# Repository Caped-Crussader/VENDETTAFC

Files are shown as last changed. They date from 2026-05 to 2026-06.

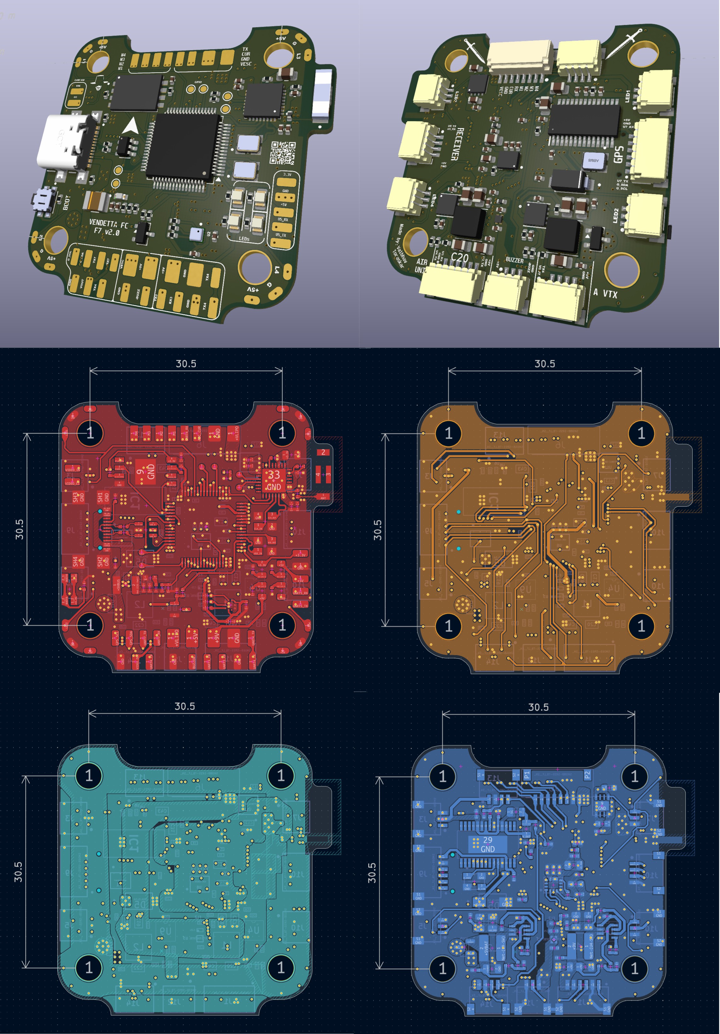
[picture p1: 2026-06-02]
VFC/imagerev2.jpg

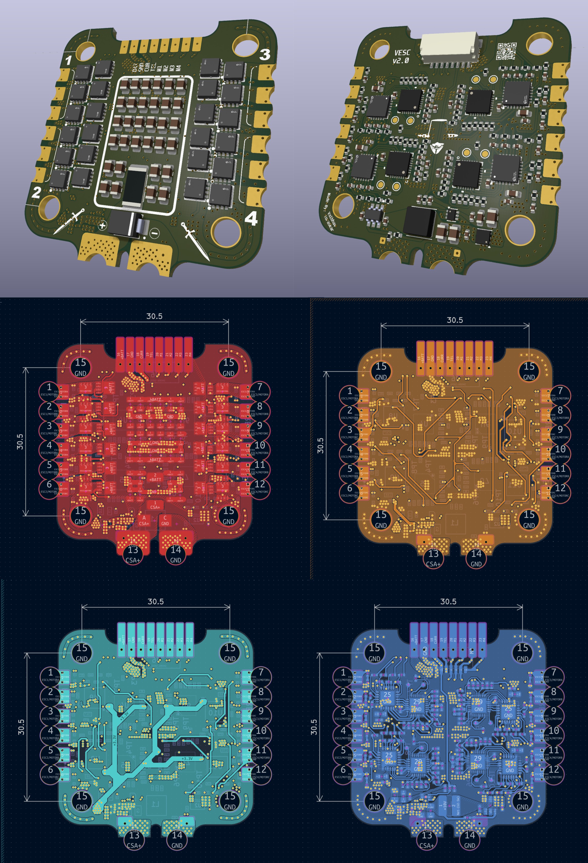
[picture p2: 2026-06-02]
VESC/imagerev2.jpg

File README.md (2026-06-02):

# VENDETTA FPV Stack

> A fully open-source, custom-designed 4-in-1 ESC and F7 Flight Controller stack for FPV multirotors, designed from scratch in KiCad.





---

## Overview

The VENDETTA stack consists of two boards designed to work together as a matched pair, built around modern components and open firmware with no proprietary dependencies.

| Board | Folder | Status |
|---|---|---|
| VENDETTA ESC (VESC) | `/VESC` | Schematic complete, layout WIP |
| VENDETTA FC (VFC) | `/VFC` | Schematic complete, layout WIP |

---

## VENDETTA ESC (VESC)

A 30×30mm 4-in-1 ESC (25A x 4) designed for 3–6S FPV multirotors.

imagerev2

> Note: 6 Layer Board, GND (plane 2 and 5) plane photos not included.

### Specifications

| Parameter | Value |
|---|---|
| MCU | Artery AT32F421GBU7 |
| Gate Driver | NSG2065Q |
| MOSFETs | SP40N03GNJ (×6 per channel, 24 total) |
| Continuous current | 25A per channel |
| Burst current | 30A per channel |
| Input voltage | 3–6S LiPo (12.6V–25.2V) |
| Motor outputs | 4× 3-phase BLDC |
| Firmware | AM32 |
| Protocols | DShot150 / DShot300 / DShot600 |
| Telemetry | Bidirectional DShot (RPM) |
| Current sensing | INA185 + 0.5mΩ Kelvin shunt |
| TVS protection | SMBJ30A |
| Bulk capacitance | 320µF (32× 10µF MLCC) |
| BEC (8V) | MP9943GQ-Z |
| BEC (3.3V) | TLV76733 |
| Mounting | 30×30mm M3 |
| Connector | JST SH 1.0mm 8-pin (SM08B-SRSS-TB) |

### ESC Block Diagram

```
LiPo ──→ TVS + Bulk Caps ──→ 4× Half-Bridge (NSG2065Q + SP40N03GNJ)
                           ──→ 8V BEC ──→ Gate Driver VCC
                           ──→ Shunt (0.5mΩ Kelvin) ──→ INA185 ──→ AT32F421
AT32F421 ──→ DShot (from FC) ──→ PWM generation ──→ NSG2065Q ──→ Motors
```

---

## VENDETTA FC (VFC)

A 30×30mm F7 Flight Controller targeting feature parity with commercial boards like the SpeedyBee F7 V3, with improvements in IMU performance and power isolation.

imagerev2

> Note: 6 Layer Board, GND (plane 2 and 5) plane photos not included.

### Specifications

| Parameter | Value |
|---|---|
| MCU | STM32F722RETx (216MHz Cortex-M4) |
| IMU | ICM-42688-P (32kHz gyro, SPI) |
| Barometer | BMP388 (I2C) |
| Blackbox | W25N04KVZEIR (512MB NAND Flash, SPI) |
| Wireless | ESP32-C3 (WiFi + BT via UART1) |
| OSD | None (digital OSD via MSP DisplayPort) |
| Firmware | Betaflight |
| Motor outputs | 4× DShot (TIM2 CH1–CH4, PA0–PA3) |
| UARTs | 6× (UART3 OSD, UART4 DJI RX, UART5 ELRS, UART6 GPS, UART7 spare) |
| I2C | 1× (GPS compass) |
| USB | USB-C (USB 2.0 FS) |
| BEC (9V/2A) | MP9943GQ-Z |
| BEC (5V/3A) | MP9943GQ-Z |
| LDO Digital (3.3V/1A) | AP7361C |
| LDO Analog (3.3V/700mA) | NCP167AMX330 |
| Blackbox | 512MB onboard flash |
| DJI support | Air Unit / O3 via UART3+UART4 |
| GPS | UART7 + I2C (compass) |
| Receiver | UART5 (ELRS/CRSF/SBUS) |
| LED outputs | 4× |
| Buzzer | MOSFET driven |
| Mounting | 30×30mm M3 |

### FC Block Diagram

```
                    ┌─────────────────────────────┐
LiPo (via ESC) ────→│ 9V BEC → 5V BEC → 3.3V x2  │
                    │                             │
                    │  STM32F722 ←─SPI─→ ICM-42688-P (IMU)
                    │             ←─SPI─→ W25N04KV (Flash)
                    │             ←─UART1─→ ESP32-C3 (WiFi/BT)
                    │             ←─I2C─→ BMP388 (Baro)
                    │             ←─USB─→ USB-C
                    │             ──UART3/4──→ DJI Air Unit
                    │             ──UART5────→ Receiver (ELRS)
                    │             ──UART6────→ GPS
                    │             ──TIM2─────→ ESC DShot M1-M4
                    └─────────────────────────────┘
```

### Power Architecture

```
VBAT (from ESC 8-pin) ──→ 9V/2A (MP9943) ──→ DJI Air Unit
                                           ──→ 5V/3A (MP9943) ──→ JST 5V outputs
                                                               ──→ 3.3V Digital (AP7361C) ──→ STM32, ESP32, Flash
                                                               ──→ [Ferrite] ──→ 3.3V Analog (NCP167) ──→ IMU, Baro, VDDA
```

---

## Connector Pinout

### ESC → FC (JST SH 1.0mm 8-pin)

| Pin | Signal | Description |
|---|---|---|
| 1 | VBAT | Battery voltage |
| 2 | GND | Ground |
| 3 | M1 | Motor 1 DShot |
| 4 | M2 | Motor 2 DShot |
| 5 | M3 | Motor 3 DShot |
| 6 | M4 | Motor 4 DShot |
| 7 | CURR | Current sense (INA185 output) |
| 8 | TLM | ESC telemetry UART |

### FC Bottom Connectors (JST SH 1.0mm)

| Connector | Pins | Function |
|---|---|---|
| ESC | 8 | M1–M4, CURR, TLM, VBAT, GND |
| RECEIVER | 4 | +5V, GND, UART5_RX, UART5_TX |
| GPS | 6 | +5V, GND, UART6_TX, UART6_RX, SDA, SCL |
| DJI AIR UNIT | 6 | +9V, GND, UART3_TX, UART3_RX, UART4_RX, NC |
| UART5 | 4 | +5V, GND, TX, RX |
| LED 1–4 | 3 each | +5V, GND, Signal |
| BUZZER | 2 | +5V, Signal |

---

## Firmware (Not yet Completed)

### ESC — AM32

AM32 is the only supported firmware for the AT32F421 MCU.

Flash via DShot passthrough from Betaflight:
```
Betaflight Configurator → Motors → ESC Configuration → Flash All
```

Or via SWD using the exposed test pads (SWDIO/SWDCLK).

Recommended target: `AT32F421_VESC` — confirm correct pin mapping before flashing.

### FC — Betaflight

Target: `STM32F7X2` unified target or a custom target for this board.

Flash via USB DFU:
1. Hold BOOT button, plug USB-C
2. Open Betaflight Configurator → Firmware Flasher
3. Select STM32F7X2, flash

Or wirelessly via ESP32-C3 over WiFi through the SpeedyBee App.

---

## Repository Structure

```
VENDETTAFC/
├── VESC/
│   ├── VESC.kicad_pro
│   ├── VESC.kicad_sch
│   ├── ESC1.kicad_sch        # Per-channel ESC subsheet
│   └── ...
├── VFC/
│   ├── VENDETTAFC.kicad_pro
│   ├── VENDETTAFC.kicad_sch  # Top-level schematic
│   ├── interface.kicad_sch   # Connectors and I/O
│   ├── pwr.kicad_sch         # Power management
│   ├── sensor.kicad_sch      # IMU, baro, flash, ESP32
│   └── ...
└── README.md
```

---

## Design Files

Both boards are designed in **KiCad 10**. All schematic symbols and footprints use standard KiCad libraries plus LCSC-sourced footprints where needed.

To open:
```
KiCad 10 → Open Project → select .kicad_pro file
```

---

## Status

- [x] ESC schematic complete
- [x] FC schematic complete  
- [x] ESC PCB layout
- [x] FC PCB layout
- [x] Gerber generation
- [ ] First prototype order
- [ ] Firmware bringup
- [ ] Testing and validation

---

## License

Hardware design files are released under the **CERN Open Hardware Licence Version 2 - Strongly Reciprocal (CERN-OHL-S v2)**.

You are free to study, modify, distribute, and manufacture this hardware, provided derivatives are released under the same license with attribution.

---

## Author

Designed by **Caped-Crussader**

> Contributions, bug reports, and suggestions welcome via Issues.

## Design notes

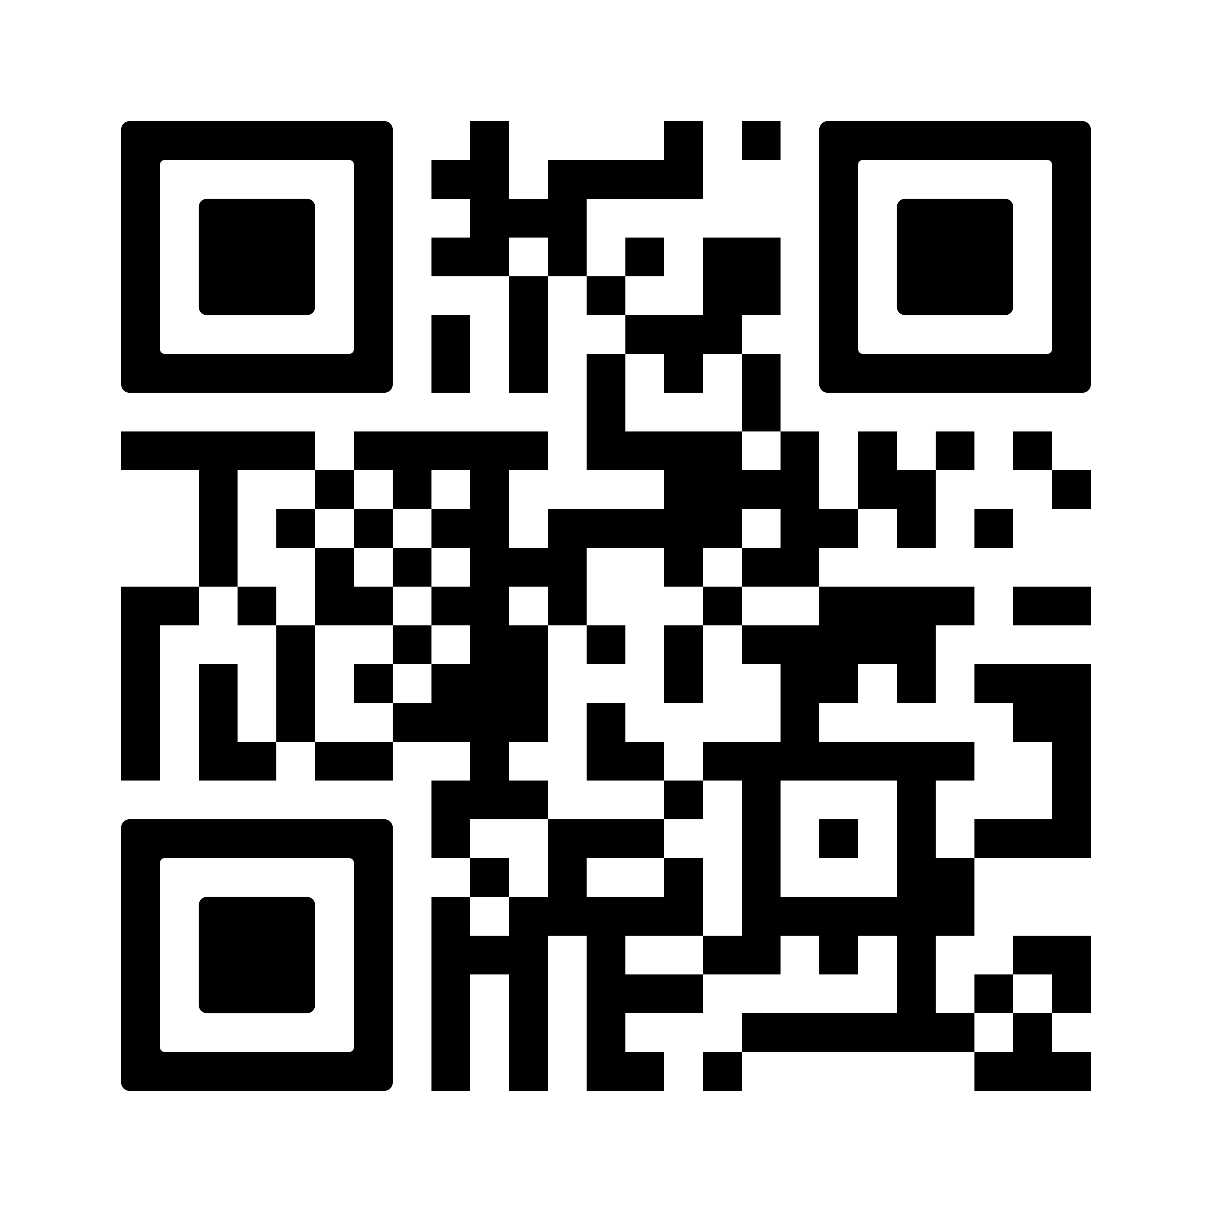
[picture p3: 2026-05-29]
VFC/https_github_com_Caped-Crussader.png

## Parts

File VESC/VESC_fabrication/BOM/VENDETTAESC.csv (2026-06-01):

Value | Description | Reference | Footprint | Qty | MANUFACTURER | Manufacturer Part Number | LCSC | Distributor Link | Datasheet
220pF | Unpolarized capacitor SMD 0402 | C87,C88,C89,C90,C91,C92,C93,C94,C95,C96,C97,C98 | Capacitor_SMD:C_0402_1005Metric | 12 | YAGEO | AC0402KRX7R0BB221 | C7209937 | https://www.lcsc.com/product-detail/C7209937.html | https://www.lcsc.com/datasheet/C7209937.pdf
100nF | Unpolarized capacitor SMD 0402 | C1,C2,C3,C6,C7,C8,C11,C12,C13,C14,C15,C16,C17,C18,C19,C20,C21,C22,C23,C24,C25,C26,C59,C60,C61,C62,C63,C64,C65,C66,C75,C76,C77,C78 | Capacitor_SMD:C_0402_1005Metric | 34 | muRata | GRM155R71H104KE14D | C77020 | https://www.lcsc.com/product-detail/C77020.html | https://www.lcsc.com/datasheet/C77020.pdf
1uF | Unpolarized capacitor SMD 0402 | C71,C72,C73,C74 | Capacitor_SMD:C_0402_1005Metric | 4 | Samsung Electro-Mechanics | CL05A105KO5NNNC | C29266 | https://www.lcsc.com/product-detail/C29266.html | https://www.lcsc.com/datasheet/C29266.pdf
4.7uF | Unpolarized capacitor SMD 0603 | C9,C67,C68,C69,C70 | Capacitor_SMD:C_0603_1608Metric | 5 | Samsung Electro-Mechanics | CL10A475KO8NNNC | C19666 | https://www.lcsc.com/product-detail/C19666.html | https://www.lcsc.com/datasheet/C19666.pdf
10uF | Unpolarized capacitor SMD 0805 | C27,C28,C29,C30,C31,C32,C33,C34,C35,C36,C37,C38,C39,C40,C41,C42,C43,C44,C45,C46,C47,C48,C49,C50,C51,C52,C53,C54,C55,C56,C57,C58 | Capacitor_SMD:C_0805_2012Metric | 32 | Samsung Electro-Mechanics | CL21A106KBYQNNE | C2932476 | https://www.lcsc.com/product-detail/C2932476.html?s_z=n_q_C2932476&globalKeyword=C2932476 | https://www.lcsc.com/datasheet/C2932476.pdf
10uH | Molded power inductor SMD | L1 | Inductor_SMD:L_Changjiang_FTC404020S | 1 | FAUKU | GXTC0420-100-MT | C53198553 | https://www.lcsc.com/product-detail/C53198553.html?s_z=s_p_GXTC0420-100-MT | https://www.lcsc.com/datasheet/C53198553.pdf
22uF | Unpolarized capacitor SMD 0805 | C4,C5,C10 | Capacitor_SMD:C_0805_2012Metric | 3 | Samsung Electro-Mechanics | CL21A226MAYNNNE | C602037 | https://www.lcsc.com/product-detail/C602037.html | https://www.lcsc.com/datasheet/C602037.pdf
0.5mR | Resistor shunt 0.5mΩ ±5% 6W 2512 | R1 | Resistor_SMD:R_2512_6332Metric | 1 | RESI | EBWM2512JL500S9 | C19679480 | https://www.lcsc.com/product-detail/C19679480.html | https://www.lcsc.com/datasheet/C19679480.pdf
4.7 | Resistor SMD 0402 | R90,R91,R92,R93,R94,R95,R96,R97,R98,R99,R100,R101 | Resistor_SMD:R_0402_1005Metric | 12 | UNI-ROYAL | 0402WGJ047JTCE | C25169 | https://www.lcsc.com/product-detail/C25169.html | https://www.lcsc.com/datasheet/C25169.pdf
15R | Resistor SMD 0402 | R53,R54,R55,R56,R57,R58,R59,R60,R61,R62,R63,R64,R65,R66,R67,R68,R69,R70,R71,R72,R73,R74,R75,R76 | Resistor_SMD:R_0402_1005Metric | 24 | UNI-ROYAL | 0402WGF150JTCE | C25083 | https://www.lcsc.com/product-detail/C25083.html | https://www.lcsc.com/datasheet/C25083.pdf
220 | Resistor SMD 0402 | R13,R14,R15,R16 | Resistor_SMD:R_0402_1005Metric | 4 | UNI-ROYAL | 0402WGJ0220TCE | C25152 | https://www.lcsc.com/product-detail/C25152.html | https://www.lcsc.com/datasheet/C25152.pdf
1K | Resistor SMD 0402 | R2,R5,R6,R7,R8,R21,R22,R23,R24,R30,R33,R36,R39,R42,R45,R48,R51 | Resistor_SMD:R_0402_1005Metric | 17 | YAGEO | RC0402FR-071KL | C106235 | https://www.lcsc.com/product-detail/C106235.html | https://www.lcsc.com/datasheet/C106235.pdf
10K | Resistor SMD 0402 | R4,R9,R10,R11,R12,R17,R18,R19,R20,R25,R26,R27,R28,R29,R31,R32,R34,R35,R37,R38,R40,R41,R43,R44,R46,R47,R49,R50,R52,R77 | Resistor_SMD:R_0402_1005Metric | 30 | YAGEO | RC0402JR-0710KL | C60489 | https://www.lcsc.com/product-detail/C60489.html | https://www.lcsc.com/datasheet/C60489.pdf
124K | Resistor SMD 0402 | R3 | Resistor_SMD:R_0402_1005Metric | 1 | UNI-ROYAL | 0402WGF1243TCE | C36777 | https://www.lcsc.com/product-detail/C36777.html | https://www.lcsc.com/datasheet/C36777.pdf
AT32F421G8U7 | ARM 32-bit Cortex-M4 microcontroller | U4,U5,U6,U7 | AT32F421G8U7:QFN28_4x4_ART | 4 | ARTERY | AT32F421G8U7 | C2765098 | https://www.lcsc.com/product-detail/C2765098.html?s_z=s_p_AT32F421G8U7 | https://www.lcsc.com/datasheet/C2765098.pdf
FerriteBead | Ferrite bead | FB1,FB2,FB3,FB4 | Inductor_SMD:L_0402_1005Metric | 4 | FH | CBW100505U101T | C124089 | https://www.lcsc.com/product-detail/C124089.html?s_z=n_q_t_ferrite%2520bead | https://www.lcsc.com/datasheet/C124089.pdf
INA185A2 | 1 5uV -200mV~26V 2V/us 210kHz 100dB 75uA 200uA 50V/V SOT-563 Instrumentation, Op Amps, Buffer Amps RoHS | U1 | Package_TO_SOT_SMD:SOT-563 | 1 | Texas Instruments | INA185A2IDRLR | C2059320 | https://www.lcsc.com/product-detail/C2059320.html?s_z=s_p_INA185A2IDRLR | https://www.lcsc.com/datasheet/C2059320.pdf
LMR51420YFDDCR | SIMPLE SWITCHER® power converter 4.5-V to 36-V, 2-A, synchronous buck with 40-µA IQ | U2 | LMR51420YDDCR:SOT95P280X110-6N | 1 | Texas Instruments | LMR51420YFDDCR | C7296200 | https://www.lcsc.com/product-detail/C7296200.html?s_z=n_q_C7296200&globalKeyword=C7296200 | https://www.lcsc.com/datasheet/C7296200.pdf
NSG2065Q | Integrated BSD Three-Phase Half Bridge MOSFET/IGBT Gate Driver | U8,U9,U10,U11 | NSG2065Q:QFN-24_L4.0-W4.0-P0.50-TL-EP2.8 | 4 | WXNSIC | NSG2065Q | C41414478 | https://www.lcsc.com/product-detail/C41414478.html?s_z=n_q_C41414478&globalKeyword=C41414478 | https://www.lcsc.com/datasheet/C41414478.pdf
SM08B-SRSS-TB | Connector Header Surface Mount, Right Angle 8 position 0.039 (1.00mm) | J6 | Connector_JST:JST_SH_SM08B-SRSS-TB_1x08-1MP_P1.00mm_Horizontal | 1 | JST | SM08B-SRSS-TB(LF)(SN) | C160407 | https://www.lcsc.com/product-detail/C160407.html?s_z=n_q_C160407&globalKeyword=C160407 | https://www.lcsc.com/datasheet/C160407.pdf
SMBJ30A | 600W, 30V, Unidirectional, TVS | D1 | SMBJ30A:DIOM4336X265N | 1 | DIODES | SMBJ30A-13-F | C135065 | https://www.lcsc.com/product-detail/C135065.html?s_z=s_p_SMBJ30A | https://www.lcsc.com/datasheet/C135065.pdf
SP40N03GNJ | 40V N-Channel Power MOSFET | Q1,Q2,Q3,Q4,Q5,Q6,Q7,Q8,Q9,Q10,Q11,Q12,Q13,Q14,Q15,Q16,Q17,Q18,Q19,Q20,Q21,Q22,Q23,Q24 | SP40N03GNJ:POWERPAK-1212-8_L3.0-W3.0-P0.65-LS3.3-BL | 24 | Siliup | SP40N03GNJ | C22466709 | https://www.lcsc.com/product-detail/C22466709.html?s_z=n_q_C22466709&globalKeyword=C22466709 | https://www.lcsc.com/datasheet/C22466709.pdf
TestPoint | test point | TP3,TP4,TP5,TP6,TP7,TP8,TP9,TP10 | TestPoint:TestPoint_Pad_D1.0mm | 8 | - | - | - | - | -
TLV76733DRVx | 1A Precision Linear Voltage Regulator, with enable pin, Fixed Output 3.3V, WSON6 | U3 | Package_SON:WSON-6-1EP_2x2mm_P0.65mm_EP1x1.6mm_ThermalVias | 1 | Texas Instruments | TLV76733DRVR | C2848334 | https://www.lcsc.com/product-detail/C2848334.html?s_z=n_q_C2848334&globalKeyword=C2848334 | https://www.lcsc.com/datasheet/C2848334.pdf
VESC | Custom symbol and footprint for the board having all the testpoints and smd pads integrated. | U12 | VESC:VESC | 1 | - | - | - | - | -

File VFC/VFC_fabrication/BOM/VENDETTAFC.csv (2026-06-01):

Value | Description | Reference | Footprint | Qty | MANUFACTURER | MANUFACTURER PART NUMBER | LCSC | Distributor Link | Datasheet
1.8nH | Inductor SMD 0402 | L3 | Inductor_SMD:L_0402_1005Metric | 1 | muRata | LQG15HS1N8S02D | C77107 | https://www.lcsc.com/product-detail/C77107.html?s_z=s_p_LQG15HS1N8S02D | https://www.lcsc.com/datasheet/C77107.pdf
10nF | Unpolarized capacitor SMD 0402 | C10,C33 | Capacitor_SMD:C_0402_1005Metric | 2 | Samsung Electro-Mechanics | CL05B103KB5NNNC | C15195 | https://www.lcsc.com/product-detail/C15195.html | https://www.lcsc.com/datasheet/C15195.pdf
100nF | Unpolarized capacitor SMD 0402 | C1,C2,C3,C4,C6,C11,C14,C15,C16,C23,C26,C27,C28,C29,C30,C32,C35,C36,C38,C41,C42,C44,C45,C46,C47,C48,C49,C50 | Capacitor_SMD:C_0402_1005Metric | 28 | Samsung Electro-Mechanics | CL05A104KA5NNNC | C100072 | https://www.lcsc.com/product-detail/C100072.html | https://www.lcsc.com/datasheet/C100072.pdf
1uF | Unpolarized capacitor SMD 0805 | C7 | Capacitor_SMD:C_0805_2012Metric | 1 | Samsung Electro-Mechanics | CL21B105KOFNNNE | C24123 | https://www.lcsc.com/product-detail/C24123.html | https://www.lcsc.com/datasheet/C24123.pdf
1uF | Unpolarized capacitor SMD 0402 | C24,C25,C34,C39 | Capacitor_SMD:C_0402_1005Metric | 4 | Samsung Electro-Mechanics | CL05A105KO5NNNC | C29266 | https://www.lcsc.com/product-detail/C29266.html | https://www.lcsc.com/datasheet/C29266.pdf
2.2uF | Unpolarized capacitor SMD 0402 | C8,C9 | Capacitor_SMD:C_0402_1005Metric | 2 | Samsung Electro-Mechanics | CL05A225KP5NSNC | C107369 | https://www.lcsc.com/product-detail/C107369.html | https://www.lcsc.com/datasheet/C107369.pdf
4.7uF | Unpolarized capacitor SMD 0603 | C5,C12,C13 | Capacitor_SMD:C_0603_1608Metric | 3 | Samsung Electro-Mechanics | CL10A475KO8NNNC | C19666 | https://www.lcsc.com/product-detail/C19666.html | https://www.lcsc.com/datasheet/C19666.pdf
10uF | Unpolarized capacitor SMD 0805 | C18,C21,C37 | Capacitor_SMD:C_0805_2012Metric | 3 | Samsung Electro-Mechanics | CL21A106KBYQNNE | C2932476 | https://www.lcsc.com/product-detail/C2932476.html | https://www.lcsc.com/datasheet/C2932476.pdf
10uH | Molded power inductor SMD | L1,L2 | Inductor_SMD:L_Changjiang_FTC404020S | 2 | FAUKU | GXTC0420-100-MT | C53198553 | https://www.lcsc.com/product-detail/C53198553.html?s_z=s_p_GXTC0420-100-MT | https://www.lcsc.com/datasheet/C602037.pdf
22uF | Unpolarized capacitor SMD 0805 | C17,C19,C31,C40,C43 | Capacitor_SMD:C_0805_2012Metric | 5 | Chinocera | HGC0805R5226M350NSLJ | C22367832 | https://www.lcsc.com/product-detail/C22367832.html | https://www.lcsc.com/datasheet/C22367832.pdf
47uF | Unpolarized capacitor SMD 0805 | C20,C22 | Capacitor_SMD:C_0805_2012Metric | 2 | Samsung Electro-Mechanics | CL21A476MPYNNWE | C5596752 | https://www.lcsc.com/product-detail/C5596752.html | https://www.lcsc.com/datasheet/C5596752.pdf
20 | Resistor SMD 0402 | R10,R13 | Resistor_SMD:R_0402_1005Metric | 2 | YAGEO | RC0402FR-0720RL | C138031 | https://www.lcsc.com/product-detail/C138031.html | https://www.lcsc.com/datasheet/C138031.pdf
47 | Resistor SMD 0402 | R18 | Resistor_SMD:R_0402_1005Metric | 1 | YAGEO | RC0402FR-0747RL | C137973 | https://www.lcsc.com/product-detail/C137973.html | https://www.lcsc.com/datasheet/C137973.pdf
75 | Resistor SMD 0402 | R23,R30,R38 | Resistor_SMD:R_0402_1005Metric | 3 | YAGEO | RC0402JR-0775RL | C137841 | https://www.lcsc.com/product-detail/C137841.html | https://www.lcsc.com/datasheet/C137841.pdf
80 | Resistor SMD 0402 | R2,R3 | Resistor_SMD:R_0402_1005Metric | 2 | YAGEO | RC0402FR-0780R6L | C185392 | https://www.lcsc.com/product-detail/C185392.html | https://www.lcsc.com/datasheet/C185392.pdf
220 | Resistor SMD 0402 | R21,R31 | Resistor_SMD:R_0402_1005Metric | 2 | YAGEO | RC0402FR-07220RL | C112291 | https://www.lcsc.com/product-detail/C112291.html | https://www.lcsc.com/datasheet/C112291.pdf
1K | Resistor SMD 0402 | R22,R34 | Resistor_SMD:R_0402_1005Metric | 2 | YAGEO | RC0402FR-071KL | C106235 | https://www.lcsc.com/product-detail/C106235.html | https://www.lcsc.com/datasheet/C106235.pdf
2K | Resistor SMD 0402 | R17 | Resistor_SMD:R_0402_1005Metric | 1 | YAGEO | RC0402FR-072KL | C60488 | https://www.lcsc.com/product-detail/C60488.html | https://www.lcsc.com/datasheet/C60488.pdf
2.2K | Resistor SMD 0402 | R25,R26 | Resistor_SMD:R_0402_1005Metric | 2 | YAGEO | RC0402JR-072K2L | C163447 | https://www.lcsc.com/product-detail/C163447.html | https://www.lcsc.com/datasheet/C163447.pdf
3K92 | Resistor SMD 0402 | R9 | Resistor_SMD:R_0402_1005Metric | 1 | YAGEO | RC0402FR-073K9L | C131467 | https://www.lcsc.com/product-detail/C131467.html | https://www.lcsc.com/datasheet/C131467.pdf
4.7K | Resistor SMD 0402 | R27,R28,R29 | Resistor_SMD:R_0402_1005Metric | 3 | YAGEO | RC0402FR-074K7L | C105871 | https://www.lcsc.com/product-detail/C105871.html | https://www.lcsc.com/datasheet/C105871.pdf
5k1 | Resistor SMD 0402 | R1,R5,R32 | Resistor_SMD:R_0402_1005Metric | 3 | YAGEO | RC0402FR-075K1L | C105872 | https://www.lcsc.com/product-detail/C105872.html | https://www.lcsc.com/datasheet/C105872.pdf
7K5 | Resistor SMD 0402 | R15 | Resistor_SMD:R_0402_1005Metric | 1 | UNI-ROYAL | 0402WGF7501TCE | C25918 | https://www.lcsc.com/product-detail/C25918.html | https://www.lcsc.com/datasheet/C25918.pdf
10K | Resistor SMD 0402 | R4,R6,R12,R20,R24,R33,R35 | Resistor_SMD:R_0402_1005Metric | 7 | YAGEO | RC0402JR-0710KL | C60489 | https://www.lcsc.com/product-detail/C60489.html | https://www.lcsc.com/datasheet/C60489.pdf
18K | Resistor SMD 0402 | R11 | Resistor_SMD:R_0402_1005Metric | 1 | UNI-ROYAL | 0402WGF1802TCE | C25762 | https://www.lcsc.com/product-detail/C25762.html | https://www.lcsc.com/datasheet/C25762.pdf
41K2 | Resistor SMD 0402 | R8,R16 | Resistor_SMD:R_0402_1005Metric | 2 | VISHAY | CRCW040241K2FKED | C844310 | https://www.lcsc.com/product-detail/C844310.html | https://www.lcsc.com/datasheet/C844310.pdf
51K | Resistor SMD 0402 | R7,R14 | Resistor_SMD:R_0402_1005Metric | 2 | YAGEO | RC0402FR-0751KL | C107229 | https://www.lcsc.com/product-detail/C107229.html | https://www.lcsc.com/datasheet/C107229.pdf
1M | Resistor SMD 0402 | R36,R37 | Resistor_SMD:R_0402_1005Metric | 2 | YAGEO | RC0402JR-071ML | C93949 | https://www.lcsc.com/product-detail/C93949.html | https://www.lcsc.com/datasheet/C93949.pdf
120 Ohms @ 100 MHz | Ferrite Bead SMD 0402 | FL1 | Inductor_SMD:L_0402_1005Metric | 1 | TDK | MPZ1005S121CT000 | C107331 | https://www.lcsc.com/product-detail/C107331.html?s_z=n_q_t_ferrite%2520bead | https://www.lcsc.com/datasheet/C107331.pdf
220 Ohms @ 100 MHz | 220 Ohms @ 100 MHz 1 Power Line Ferrite Bead 0402 (1608 Metric) 1.4A 100mOhm | FL2 | Inductor_SMD:L_0402_1005Metric | 1 | muRata | BLM15BB221SN1D | C85818 | https://www.lcsc.com/product-detail/C85818.html?s_z=n_q_t_ferrite%2520bead | https://www.lcsc.com/datasheet/C85818.pdf
2450AT43B100E | 2.4GHz Bluetooth, Wi-Fi, WLAN Chip RF Antenna 2.4GHz ~ 2.5GHz 1.3dBi Solder Surface Mount | AT1 | 2450AT43B100E:ANTENNA_2450AT43B100E | 1 | Johanson Dielectrics | 2450AT43B100E | C2917721 | https://www.lcsc.com/product-detail/C2917721.html?s_z=s_p_2450AT43B100E | https://www.lcsc.com/datasheet/C2917721.pdf
AT7456E | Video Character Overlay Chip (OSD) | IC1 | AT7456E_KiCad:SOP65P640X120-29N | 1 | ZHONGKEWEI | AT7456E | C82351 | https://www.lcsc.com/product-detail/C82351.html?s_z=s_p_t_AT7456E | https://www.lcsc.com/datasheet/C82351.pdf
ABM8-27.000MHZ-B2-T | 27 MHz ±20ppm Crystal 18pF 50 Ohms 4-SMD, No Lead | Y1 | ABM8-27.000MHZ-B2-T:XTAL_ABM8-27.000MHZ-B2-T | 1 | ABRACON | ABM8-27.000MHZ-B2-T | C1985251 | https://www.lcsc.com/product-detail/C1985251.html?s_z=s_p_ABM8-27.000MHZ-B2-T | https://www.lcsc.com/datasheet/C1985251.pdf
AO3400A | 30V Vds, 5.7A Id, N-Channel MOSFET, SOT-23 | Q2 | Package_TO_SOT_SMD:SOT-23 | 1 | AOS | AO3400A | C20917 | https://www.lcsc.com/product-detail/C20917.html?s_z=s_p_AO3400A | https://www.lcsc.com/datasheet/C20917.pdf
AP7361C-33FGE-7 | 1A LOW DROPOUT FIXED-MODE REGULATOR WITH ENABLE | U11 | AP7361C-FGE-7:SON65P300X300X63-9N | 1 | Diodes Inc. | AP7361C-33FGE-7 | C151007 | https://www.lcsc.com/product-detail/C151007.html?s_z=s_p_AP7361C-33FGE-7 | https://www.lcsc.com/datasheet/C151007.pdf
BAT54C | dual schottky barrier diode, common cathode | D8 | Package_TO_SOT_SMD:SOT-23 | 1 | onsemi | BAT54CLT1G | C14308 | https://www.lcsc.com/product-detail/C14308.html?s_z=s_q_x_BAT54CLT1G | https://www.lcsc.com/datasheet/C14308.pdf
BMP388 | Pressure Sensor 4.35PSI ~ 18.13PSI (30kPa ~ 125kPa) Absolute - - 10-WFLGA | U2 | BMP388:XDCR_BMP388 | 1 | Bosch Sensortec | BMP388 | C779278 | https://www.lcsc.com/product-detail/C779278.html?s_z=s_p_x_BMP388 | https://www.lcsc.com/datasheet/C779278.pdf
C3E-40.000-10-1015-X-R | Crystal, 3.20mm x2.50mm,40MHz,10pF,-40-85C | Y2 | C3E-40.000-10-1015-X-R:XTAL_C3E-40.000-10-1015-X-R | 1 | YXC Crystal Oscillators | XL2EL89CPI-111YLC-40M | C5444549 | https://www.lcsc.com/product-detail/C5444549.html?s_z=n_q_%2509%2520Crystal%252040MHz | https://www.lcsc.com/datasheet/C5444549.pdf
C3E-8.000-18-3030-X-R | Crystal, 3.20mm x2.50mm,8MHz,18pF,-40-85C | Y3 | C3E-8.000-18-3030-X-R:XTAL_C3E-8.000-18-3030-X-R | 1 | YXC Crystal Oscillators | X32258MOB4SI | C2682775 | https://www.lcsc.com/product-detail/C2682775.html?s_z=n_q_8mhz%2520crystal | https://www.lcsc.com/datasheet/C2682775.pdf
ESP32-C3 | WiFi Modules (802.11) (Engineering Samples Only) SMD IC ESP32-C3, RISC-V single-core MCU, 2.4G Wi-Fi & BLE 5.0 combo, QFN 32-pin, 5*5 mm, 40 ~ 105C | U5 | ESP32-C3:QFN50P500X500X90-33N | 1 | Espressif Systems | ESP32-C3 | C2838500 | https://www.lcsc.com/product-detail/C2838500.html?s_z=s_p_x_ESP32-C3 | https://www.lcsc.com/datasheet/C2838500.pdf
EVQ-P7A01P | Black Side Tactile Switch, Single Pole Single Throw (SPST) 10 μA → 50 mA 0.65mm Surface Mount | S2 | EVQ-P7A01P:SW_EVQ-P7A01P | 1 | Panasonic Electronic Components | EVQP7A01P | C79167 | https://www.lcsc.com/product-detail/C79167.html?s_z=n_q_EVQ-P7A01P | https://www.lcsc.com/datasheet/C79167.pdf
ICM-42688-P | Accelerometer, Gyroscope, 6 Axis Sensor - Output | U6 | ICM-42688-P:PQFN50P300X250X97-14N | 1 | TDK InvenSense | ICM-42688-P | C1850418, Mouser No: 410-ICM-42688-P | https://www.lcsc.com/product-detail/C1850418.html?s_z=s_p_t_ICM-42688-P | https://www.lcsc.com/datasheet/C1850418.pdf
KT-0603R | Red 0603 Light Emitting Diodes | D7 | KT-0603R:LED_KT-0603R | 1 | Hubei KENTO Elec | KT-0603R | C2286 | https://www.lcsc.com/product-detail/C2286.html?s_z=s_p_KT-0603R | https://www.lcsc.com/datasheet/C2286.pdf
LED1 | Light emitting diode | D4 | LED_SMD:LED_0805_2012Metric | 1 | Hubei KENTO Elec | KT-0805R | C2295 | https://www.lcsc.com/product-detail/C2295.html?s_z=n_q_KT-0805 | https://www.lcsc.com/datasheet/C2295.pdf
LED2 | Light emitting diode | D1 | LED_SMD:LED_0805_2012Metric | 1 | Hubei KENTO Elec | KT-0805B | C2293 | https://www.lcsc.com/product-detail/C2293.html?s_z=n_q_KT-0805 | https://www.lcsc.com/datasheet/C2295.pdf
LED3 | Light emitting diode | D2 | LED_SMD:LED_0805_2012Metric | 1 | Hubei KENTO Elec | KT-0805Y | C2296 | https://www.lcsc.com/product-detail/C2296.html?s_z=n_q_KT-0805 | https://www.lcsc.com/datasheet/C2295.pdf
LED4 | Light emitting diode | D3 | LED_SMD:LED_0805_2012Metric | 1 | Hubei KENTO Elec | KT-0805G | C2297 | https://www.lcsc.com/product-detail/C2297.html?s_z=n_q_KT-0805 | https://www.lcsc.com/datasheet/C2295.pdf
MICROASMD010F-2 | PolySwitch Resettable PPTC microSMD Series Surface Mount | F2 | MICROASMD010F-2:FUSE_MICROASMD010F_LTF | 1 | Littelfuse | MICROSMD010F-2 | C2649903 | https://www.lcsc.com/product-detail/C2649903.html | https://www.lcsc.com/datasheet/C2649903.pdf
MP9943GQ-Z | Switching Voltage Regulators High Efficiency 3A peak,36V,Synchronous Step Down Converter | U4,U9 | MP9943GQ-Z:QFN-8_MP9943_MNP | 2 | Monolithic Power Systems (MPS) | MP9943GQ-Z | Mouser No: 946-MP9943GQ-Z | https://www.mouser.in/ProductDetail/Monolithic-Power-Systems-MPS/MP9943GQ-Z?qs=493kPxzlxfKVcyEndxwGRg%3D%3D | https://www.monolithicpower.com/en/documentview/productdocument/index/version/2/document_type/Datasheet/lang/en/sku/MP9943GQ-Z
NCP167BMX330TBG | Linear Voltage Regulator IC Positive Fixed 1 Output 700mA 4-XDFN (1x1) | U3 | NCP167BMX330TBG:VREG_NCP167BMX330TBG | 1 | Onsemi | NCP167BMX330TBG | C892227 | https://www.lcsc.com/product-detail/C892227.html?s_z=s_p_NCP167BMX330TBG | https://www.lcsc.com/datasheet/C892227.pdf
SM03B-SRSS-TB_LF__SN_ | Connector Header Surface Mount, Right Angle 3 position 0.039 (1.00mm) | J3,J5,J7,J8,J12 | SM03B-SRSS-TB_LF__SN_:JST_SM03B-SRSS-TB_LF__SN_ | 5 | HCTL | HC-1.0-3PWT | C2845362 | https://www.lcsc.com/product-detail/C2845362.html?s_z=n_q_SM03B-SRSS-TB_LF__SN_ | https://www.lcsc.com/datasheet/C2845362.pdf
SM04B-SRSS-TB_LF__SN_ | Connector Header Surface Mount, Right Angle 4 position 0.039 (1.00mm) | J10,J13,J14 | SM04B-SRSS-TB_LF__SN_:JST_SM04B-SRSS-TB_LF__SN_ | 3 | HCTL | HC-1.0-4PWT | C2845363 | https://www.lcsc.com/product-detail/C2845363.html?s_z=n_q_SM04B-SRSS-TB_LF__SN_ | https://www.lcsc.com/datasheet/C2845363.pdf
SM06B-SRSS-TB_LF__SN_ | Connector Header Surface Mount, Right Angle 6 position 0.039 (1.00mm) | J1,J9 | SM06B-SRSS-TB_LF__SN_:JST_SM06B-SRSS-TB_LF__SN_ | 2 | HCTL | HC-1.0-6PWT | C2845365 | https://www.lcsc.com/product-detail/C2845365.html?s_z=n_q_SM06B-SRSS-TB_LF__SN_ | https://www.lcsc.com/datasheet/C2845365.pdf
SM08B-SRSS-TB_LF__SN_ | Connector Header Surface Mount, Right Angle 8 position 0.039 (1.00mm) | J6 | SM08B-SRSS-TB_LF__SN_:JST_SM08B-SRSS-TB_LF__SN_ | 1 | JST | SM08B-SRSS-TB(LF)(SN) | C160407 | https://www.lcsc.com/product-detail/C160407.html?s_z=n_q_SM08B-SRSS-TB_LF__SN_ | https://www.lcsc.com/datasheet/C160407.pdf
SMAJ5.0A | 400W, 5V, Unidirectional, TVS | D5 | SMAJ5.0A:DIOM4325X250N | 1 | Littelfuse | SMAJ5.0A | C83329 | https://www.lcsc.com/product-detail/C83329.html?s_z=s_p_x_SMAJ5.0A | https://www.lcsc.com/datasheet/C83329.pdf
STM32F722RETx | STMicroelectronics Arm Cortex-M7 MCU, 512KB flash, 256KB RAM, 216 MHz, 1.7-3.6V, 50 GPIO, LQFP64 | U1 | Package_QFP:LQFP-64_10x10mm_P0.5mm | 1 | ST | STM32F722RET6 | C118207 | https://www.lcsc.com/product-detail/C118207.html?s_z=s_p_STM32F722RET6 | https://www.lcsc.com/datasheet/C118207.pdf
TestPoint | test point | TP1,TP2,TP3,TP4,TP5,TP6,TP7,TP8,TP9,TP10,TP20,TP21,TP40,TP41,TP42,TP43,TP44,TP45,TP46,TP47,TP48,TP49,TP50,TP51 | TestPoint:TestPoint_Pad_D1.0mm | 24 | - | - | - | - | -
TestPoint | test point | TP11,TP12 | TestPoint:TestPoint_Pad_D2.0mm | 2 | - | - | - | - | -
TestPoint | test point | TP13,TP14,TP15,TP16,TP18,TP19,TP23,TP24,TP25,TP26,TP27,TP28,TP29,TP30,TP32,TP33,TP34,TP35,TP36,TP38,TP39 | TestPoint:TestPoint_Pad_1.0x1.0mm | 21 | - | - | - | - | -
TestPoint | test point | TP17,TP31,TP37 | TestPoint:TestPoint_Pad_2.0x2.0mm | 3 | - | - | - | - | -
USB4940-00-A_REVA | Type C USB 2.0 Connector | J2 | USB4940-00-A_REVA:GCT_USB4940-00-A_REVA | 1 | YUWENFA | PTCFW-H22S-001 | C54829818 | https://www.lcsc.com/product-detail/C54829818.html?s_z=n_q_p_USB4940-00-A_REVA | https://www.lcsc.com/datasheet/C54829818.pdf
USBLC6-2SC6 | Very low capacitance ESD protection diode, 2 data-line, SOT-23-6 | U10 | Package_TO_SOT_SMD:SOT-23-6 | 1 | ST | USBLC6-2SC6 | C7519 | https://www.lcsc.com/product-detail/C7519.html?s_z=s_p_USBLC6-2SC6 | https://www.lcsc.com/datasheet/C7519.pdf
W25Q256JVEIQ | SPI Flash Memory with Dual/Quad SPI | U7 | W25N04KVZEIR:IC_W25N04KVZEIR | 1 | Winbond | W25Q256JVEIQ | C97522 | https://www.lcsc.com/product-detail/C97522.html?s_z=n_q_W25Q256JVEIQ | https://www.lcsc.com/datasheet/C97522.pdf

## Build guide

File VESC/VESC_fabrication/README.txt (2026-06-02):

BOARD THICKNESS: 1.6mm

EDGE CONNECTOR: NO

Number of layers:6
Material:FR-4

Min. Track/spacing: 4/4mil
Min. Hole size: 0.3mm

-------------------------------------------------
Controlled impedance: NO

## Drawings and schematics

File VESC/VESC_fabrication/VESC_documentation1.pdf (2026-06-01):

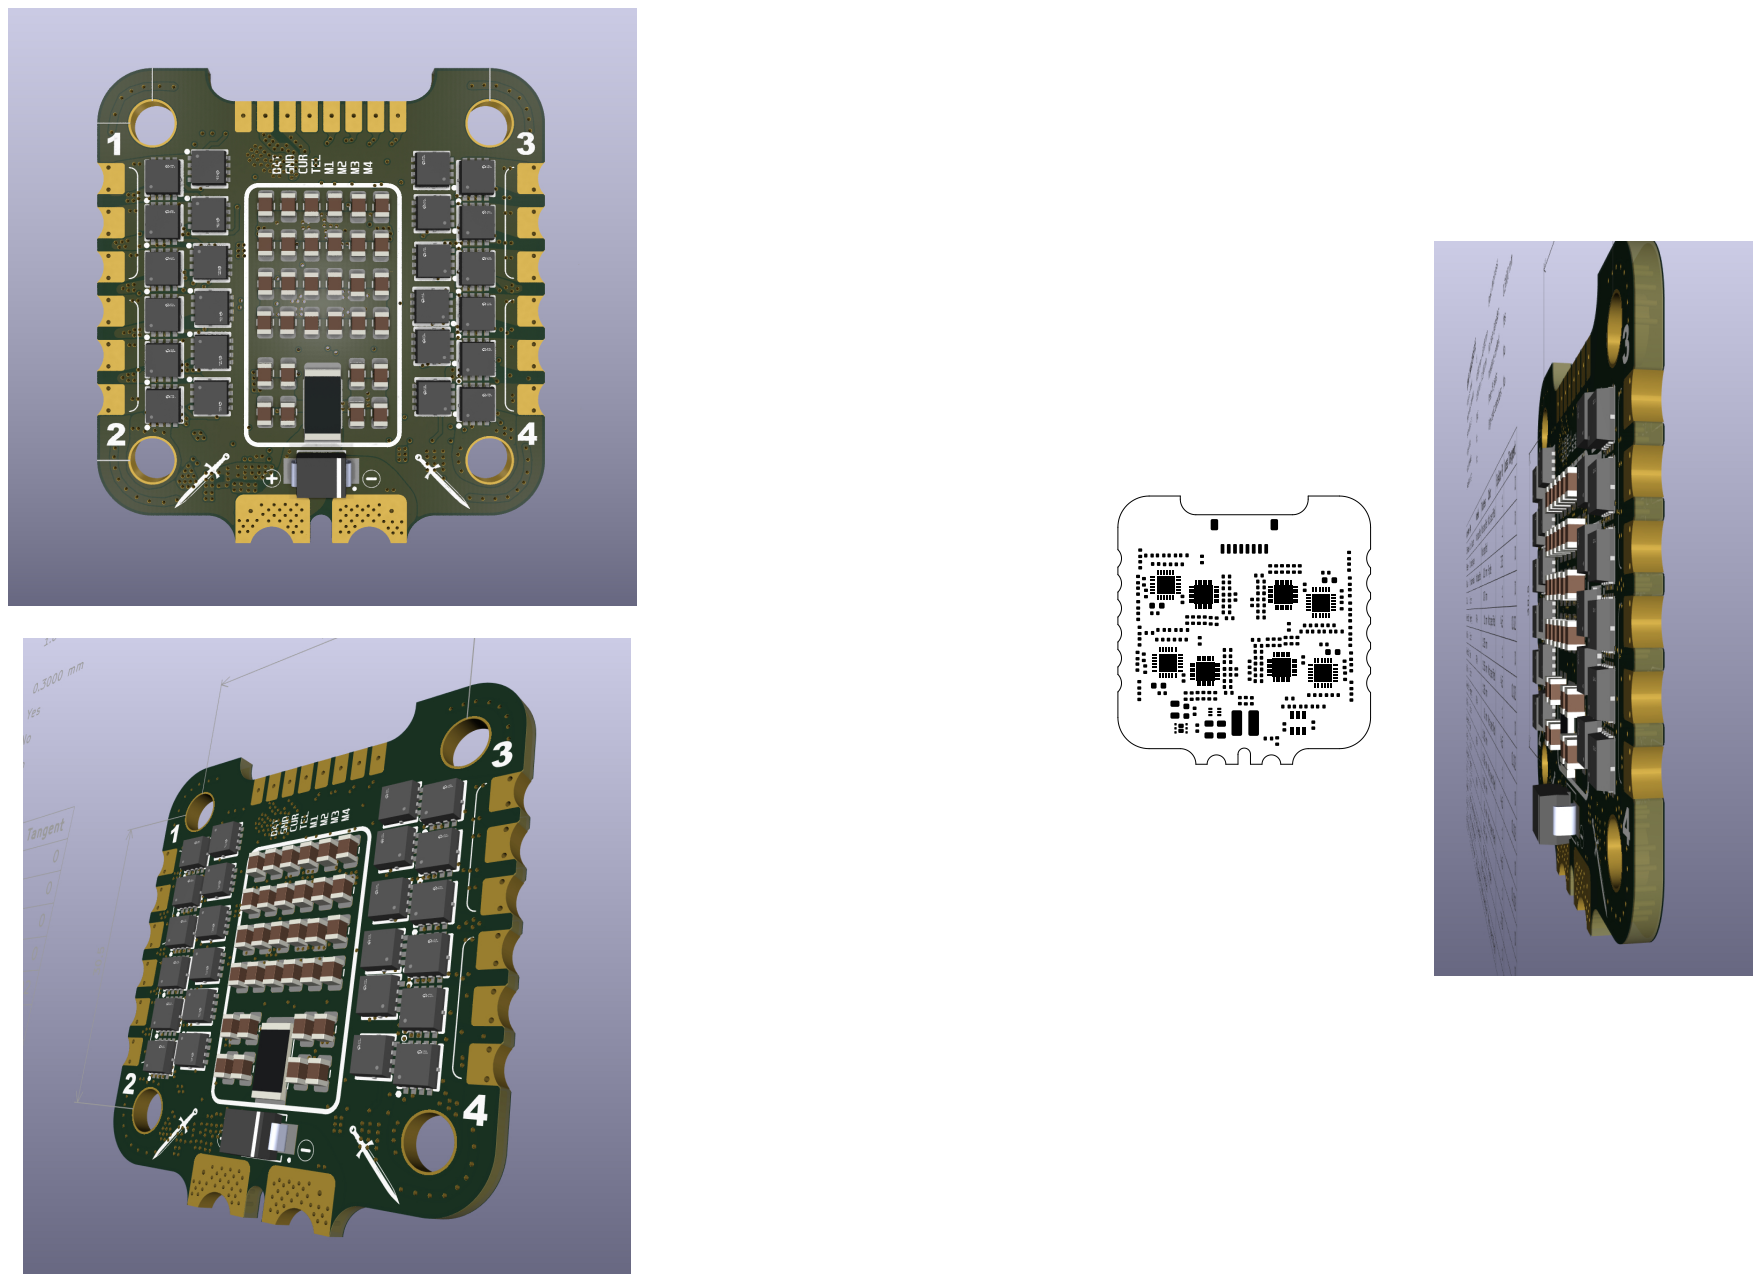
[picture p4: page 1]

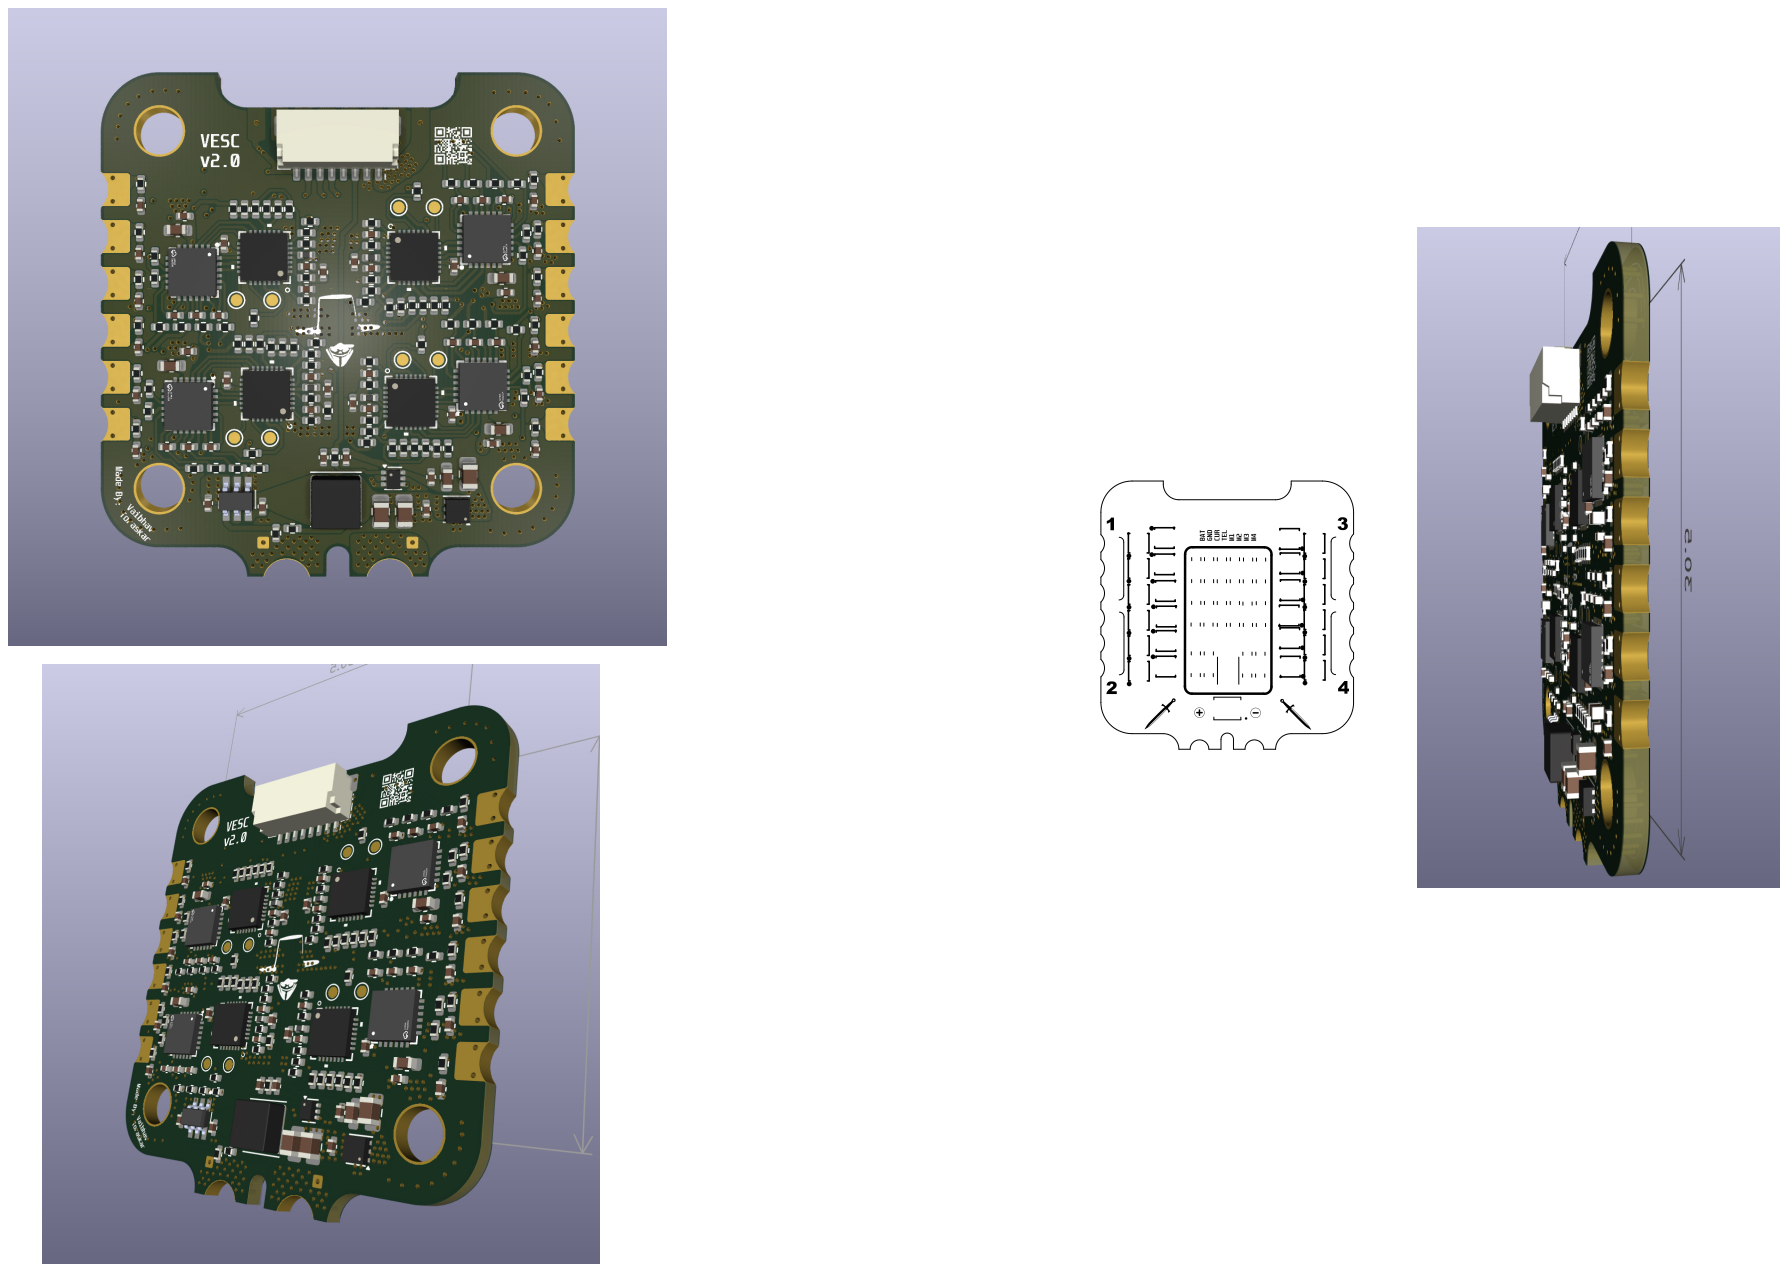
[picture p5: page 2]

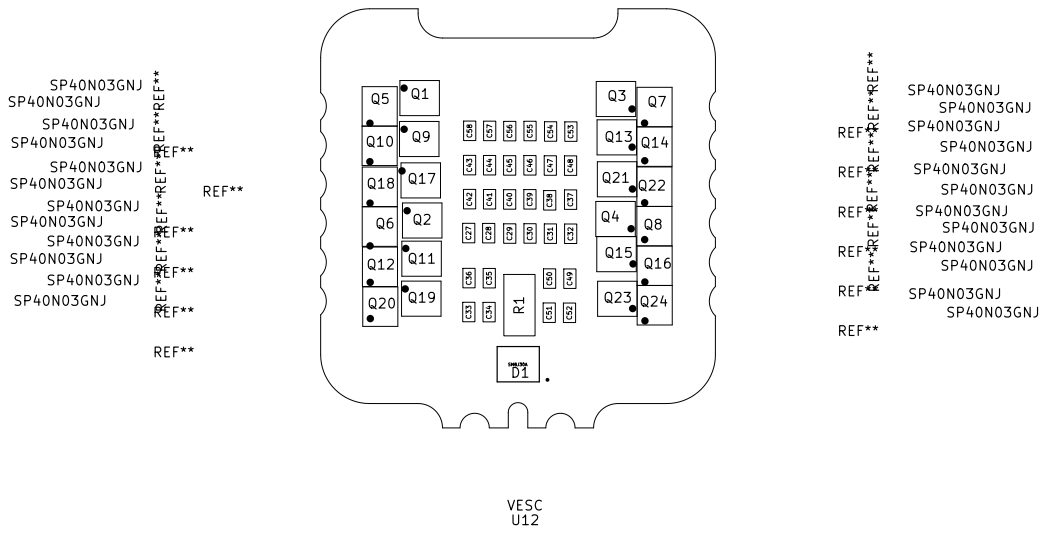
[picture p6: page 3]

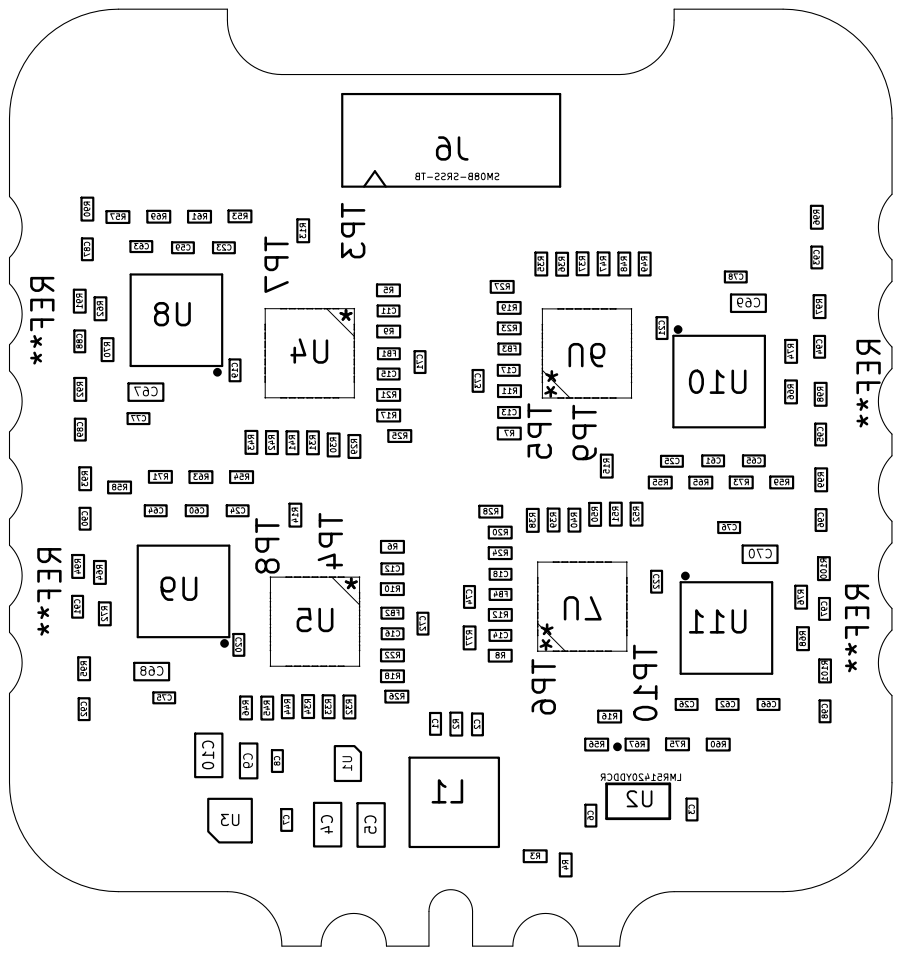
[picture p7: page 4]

L1 U2 REF** REF** REF** REF** TP9

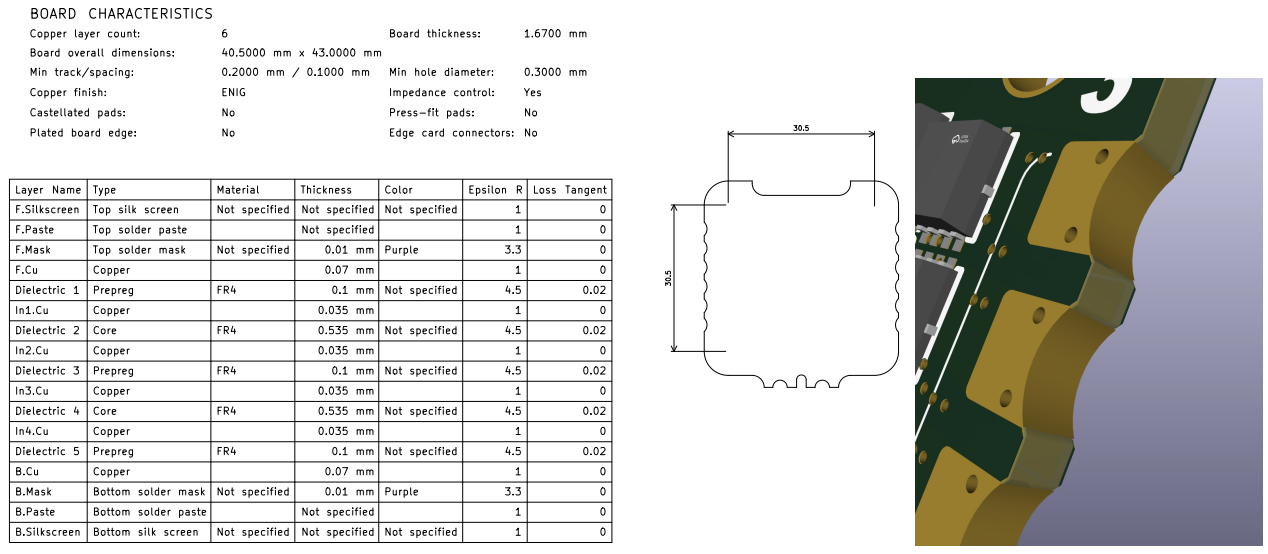
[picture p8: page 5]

Layer Name | Type | Material | Thickness | Color | Epsilon R | Loss Tangent
F.Silkscreen | Top silk screen | Not specified | Not specified | Not specified | 1 | 0
F.Paste | Top solder paste | | Not specified | | 1 | 0
F.Mask | Top solder mask | Not specified | 0.01 mm | Purple | 3.3 | 0
F.Cu | Copper | | 0.07 mm | | 1 | 0
Dielectric 1 | Prepreg | FR4 | 0.1 mm | Not specified | 4.5 | 0.02
In1.Cu | Copper | | 0.035 mm | | 1 | 0
Dielectric 2 | Core | FR4 | 0.535 mm | Not specified | 4.5 | 0.02
In2.Cu | Copper | | 0.035 mm | | 1 | 0
Dielectric 3 | Prepreg | FR4 | 0.1 mm | Not specified | 4.5 | 0.02
In3.Cu | Copper | | 0.035 mm | | 1 | 0
Dielectric 4 | Core | FR4 | 0.535 mm | Not specified | 4.5 | 0.02
In4.Cu | Copper | | 0.035 mm | | 1 | 0
Dielectric 5 | Prepreg | FR4 | 0.1 mm | Not specified | 4.5 | 0.02
B.Cu | Copper | | 0.07 mm | | 1 | 0
B.Mask | Bottom solder mask | Not specified | 0.01 mm | Purple | 3.3 | 0
B.Paste | Bottom solder paste | | Not specified | | 1 | 0
B.Silkscreen | Bottom silk screen | Not specified | Not specified | Not specified | 1 | 0

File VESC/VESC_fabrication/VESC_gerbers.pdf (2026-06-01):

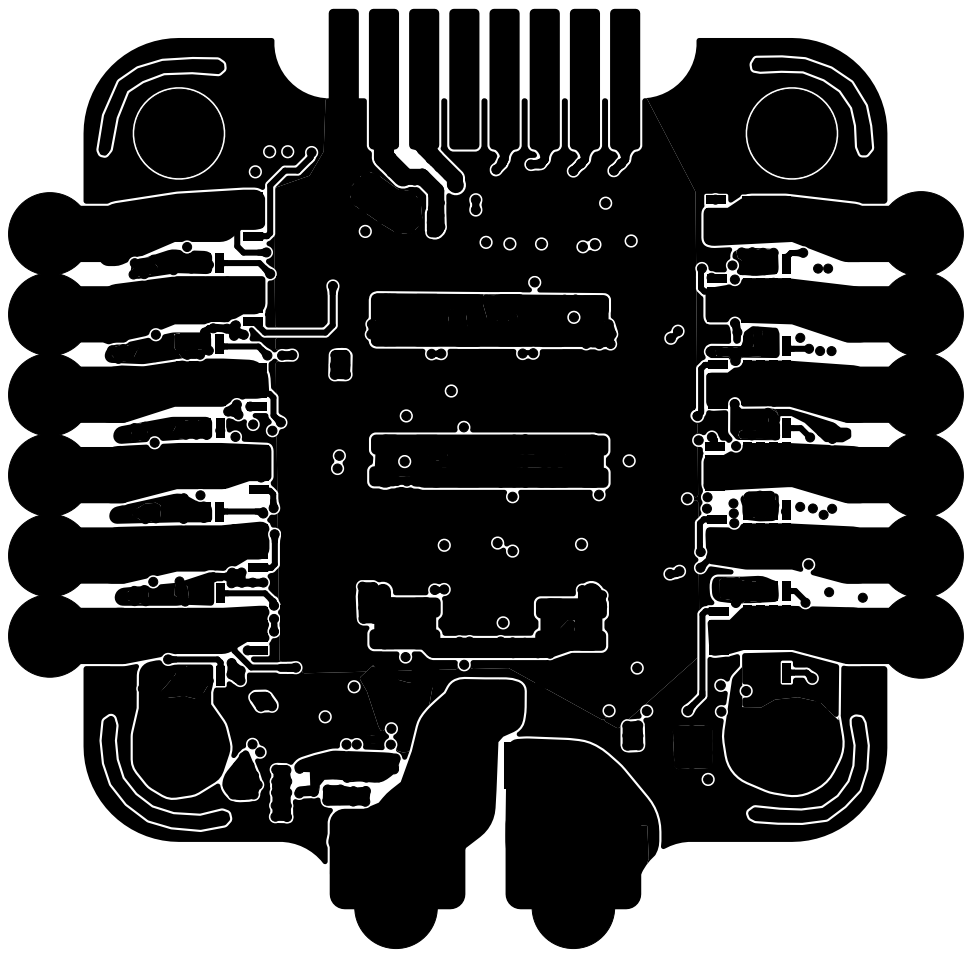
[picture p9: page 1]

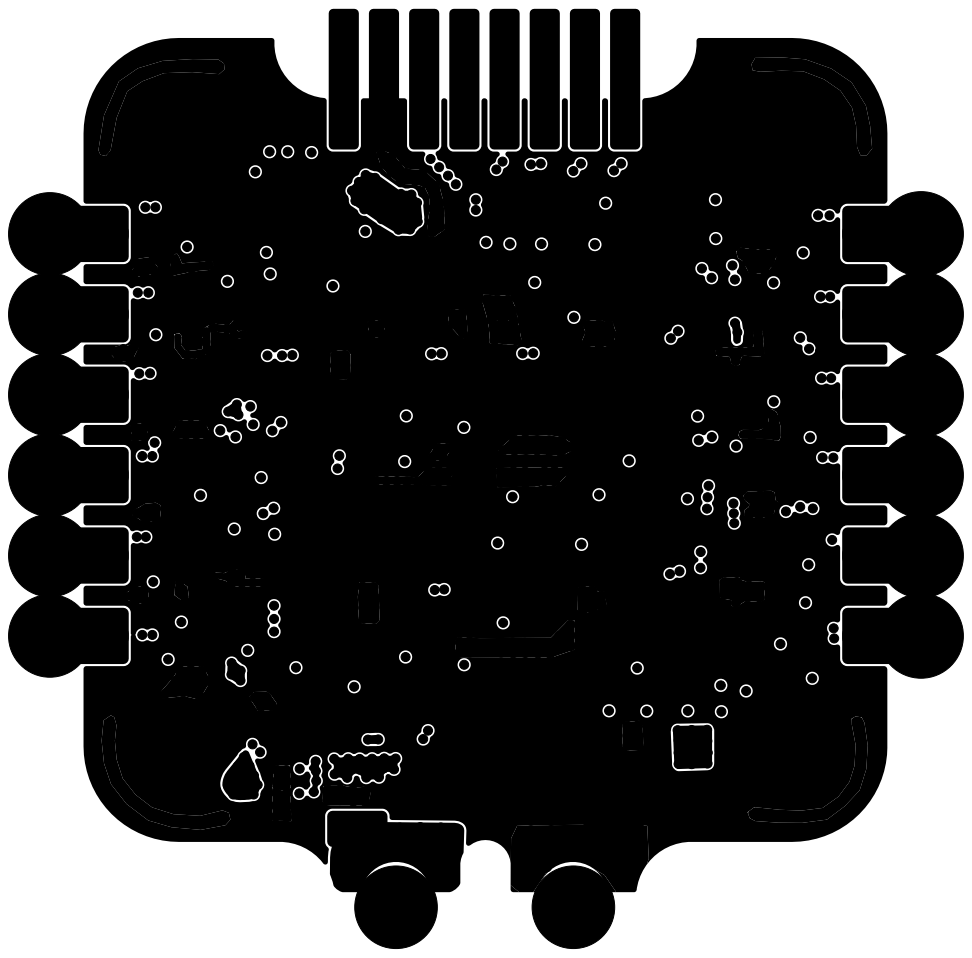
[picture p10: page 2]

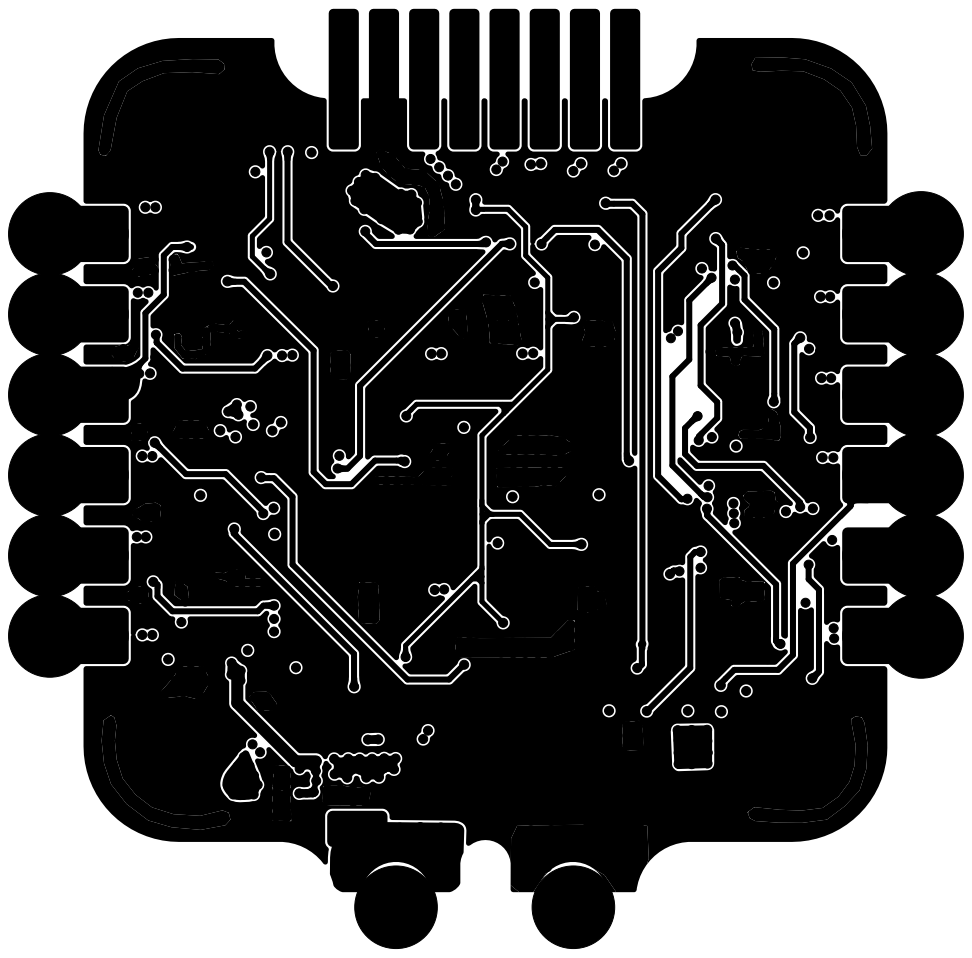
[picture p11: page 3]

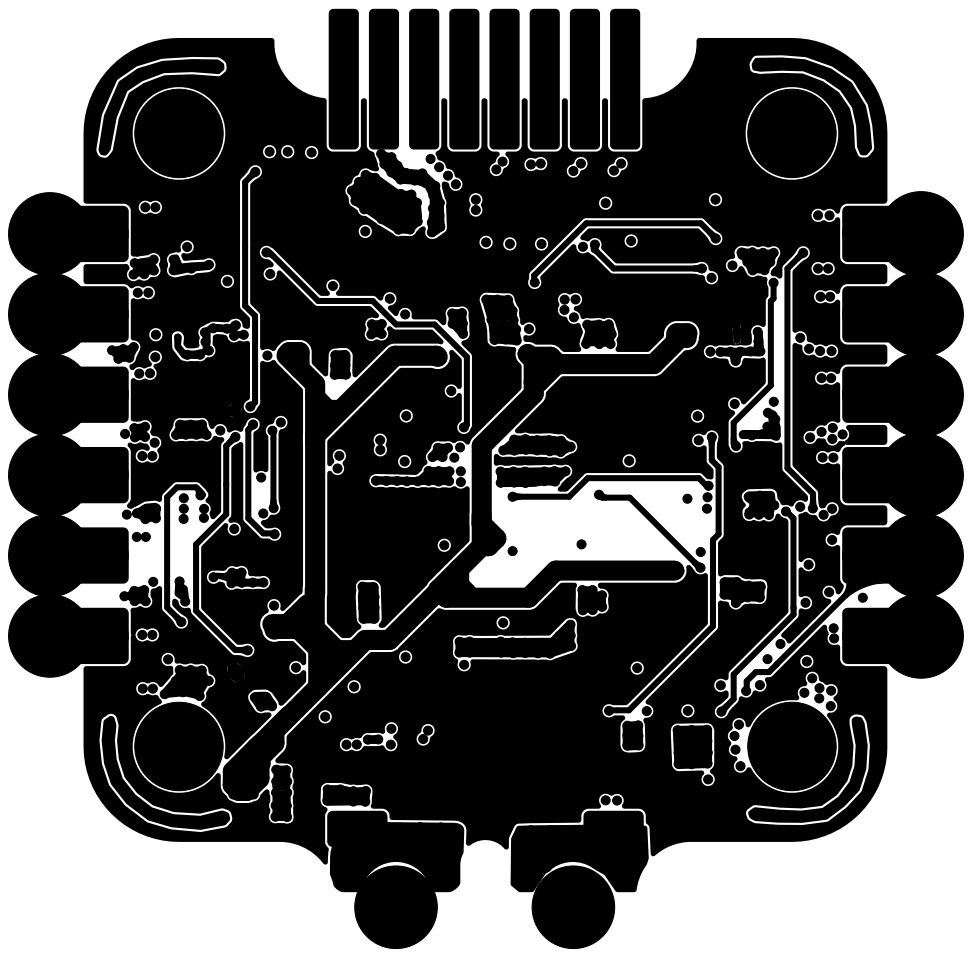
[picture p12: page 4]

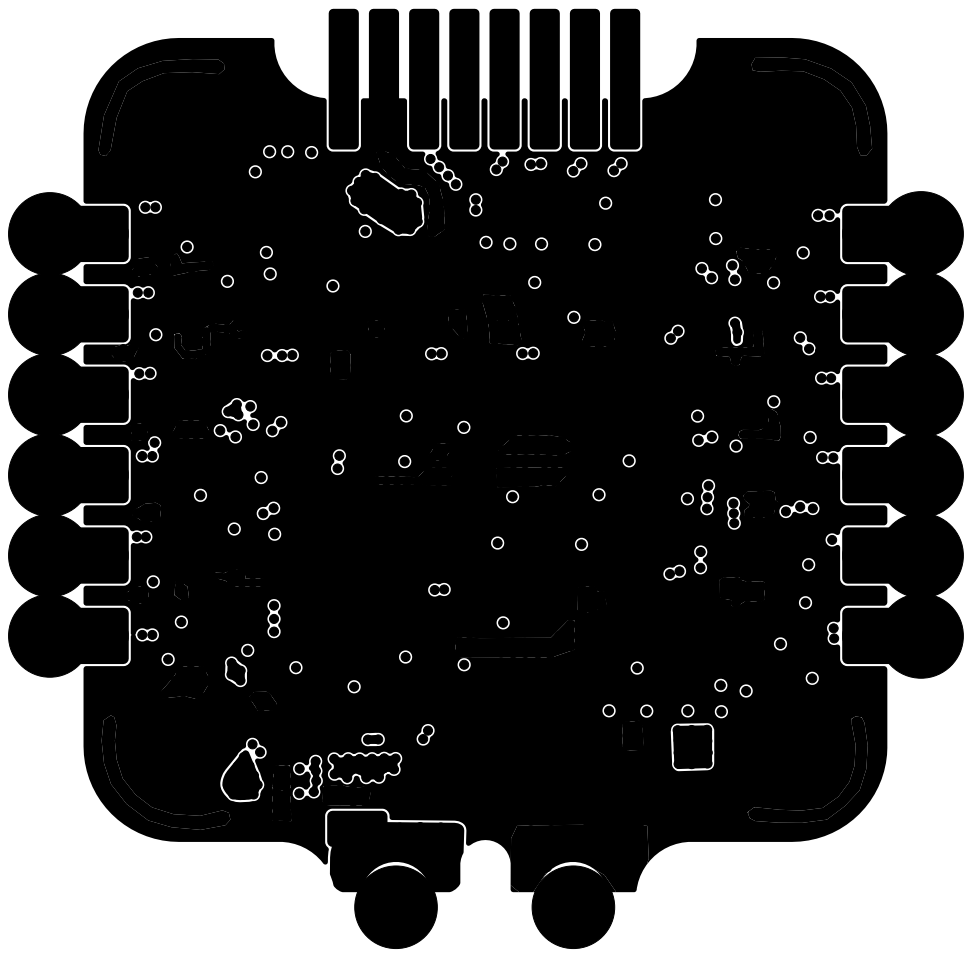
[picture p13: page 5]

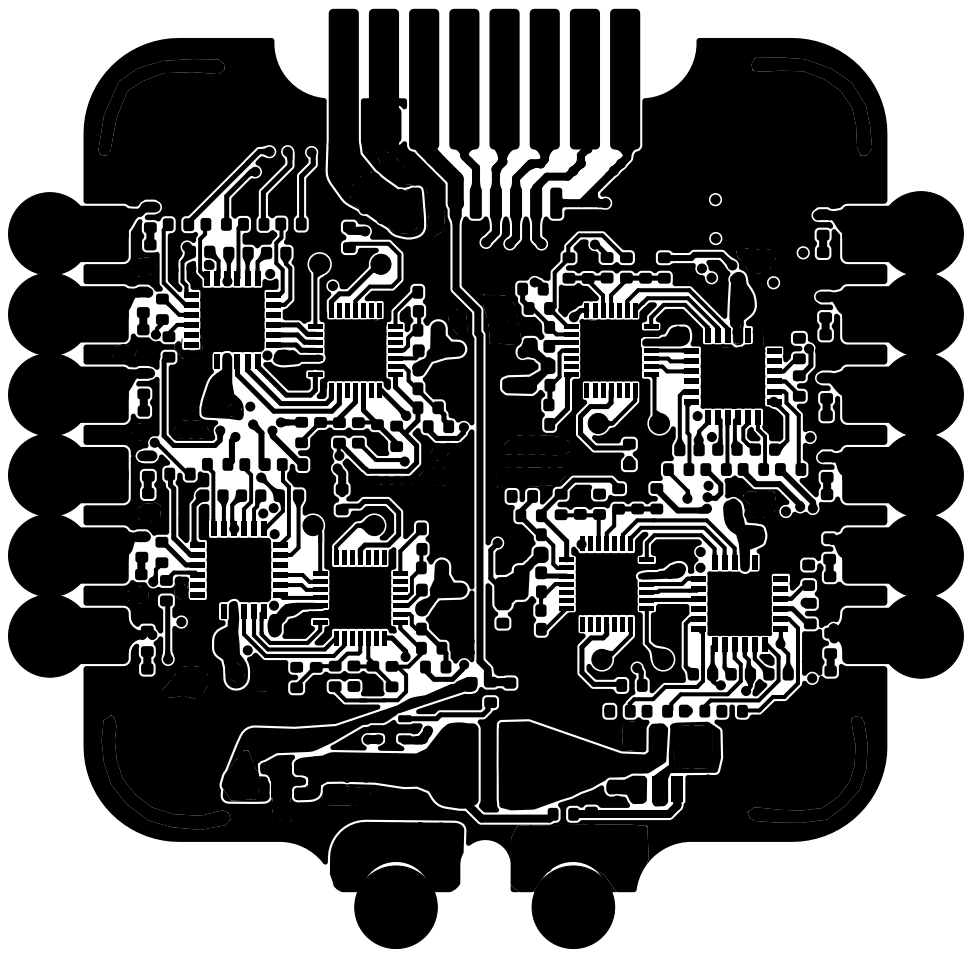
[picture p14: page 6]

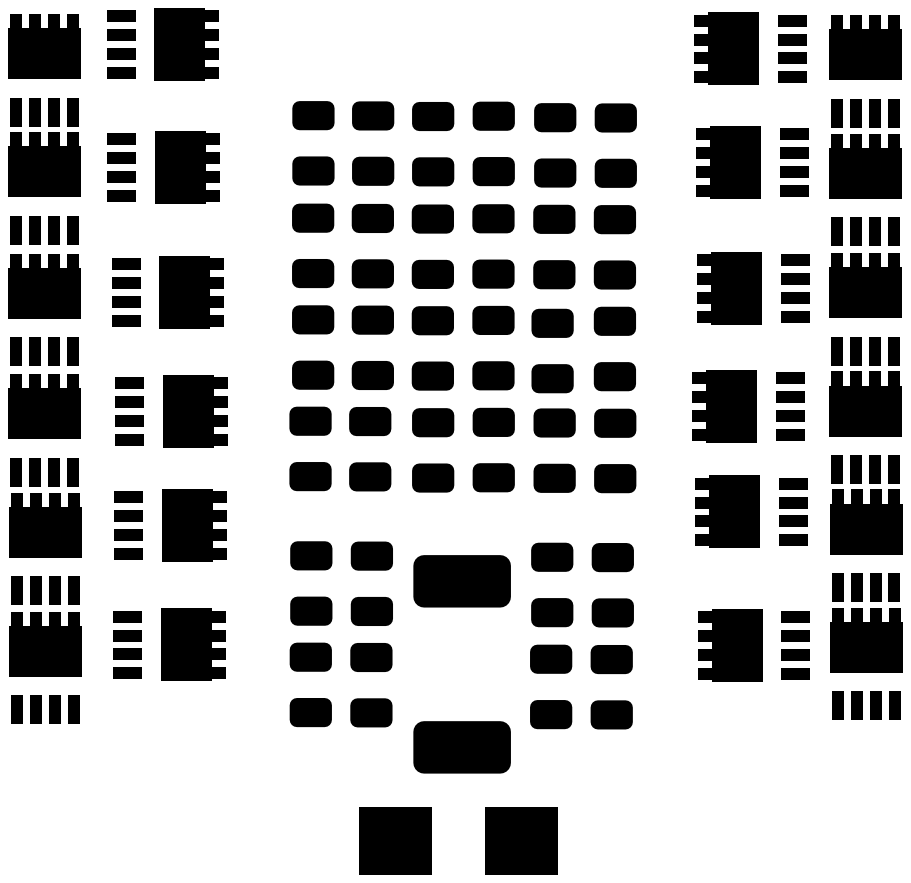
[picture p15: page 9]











L1 U2 REF** REF** REF** REF** TP9

## BOARD CHARACTERISTICS

Copper layer count: | 6 | Board thickness: | 1.6700 mm
Board overall dimensions: | 40.5000 mm x 43.0000 mm
Min track/spacing: | 0.2000 mm / 0.1000 mm | Min hole diameter: | 0.3000 mm
Copper finish: | ENIG | Impedance control: | Yes
Castellated pads: | No | Press-fit pads: | No
Plated board edge: | No | Edge card connectors: No
Layer Name | Type | Material | Thickness | Color | Epsilon R | Loss Tangent
F.Silkscreen | Top silk screen | Not specified | Not specified | Not specified | 1 | 0
F.Paste | Top solder paste | | Not specified | | 1 | 0
F.Mask | Top solder mask | Not specified | 0.01 mm | Purple | 3.3 | 0
F.Cu | Copper | | 0.07 mm | | 1 | 0
Dielectric 1 | Prepreg | FR4 | 0.1 mm | Not specified | 4.5 | 0.02
In1.Cu | Copper | | 0.035 mm | | 1 | 0
Dielectric 2 | Core | FR4 | 0.535 mm | Not specified | 4.5 | 0.02
In2.Cu | Copper | | 0.035 mm | | 1 | 0
Dielectric 3 | Prepreg | FR4 | 0.1 mm | Not specified | 4.5 | 0.02
In3.Cu | Copper | | 0.035 mm | | 1 | 0
Dielectric 4 | Core | FR4 | 0.535 mm | Not specified | 4.5 | 0.02
In4.Cu | Copper | | 0.035 mm | | 1 | 0
Dielectric 5 | Prepreg | FR4 | 0.1 mm | Not specified | 4.5 | 0.02
B.Cu | Copper | | 0.07 mm | | 1 | 0
B.Mask | Bottom solder mask | Not specified | 0.01 mm | Purple | 3.3 | 0
B.Paste | Bottom solder paste | | Not specified | | 1 | 0
B.Silkscreen | Bottom silk screen | Not specified | Not specified | Not specified | 1 | 0 | 30.5

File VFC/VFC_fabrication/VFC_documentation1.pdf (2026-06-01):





C23 SM03B-SRSS-TB_LF__SN_ C15 C16 U9 C44 R15 C5 C13 SM03B-SRSS-TB_LF__SN_ C19 C42 C14 R30 SM04B-SRSS-TB_LF__SN_ SM03B-SRSS-TB_LF__SN_ C10


Layer Name | Type | Material | Thickness | Color | Epsilon R | Loss Tangent

F.Silkscreen | Top silk screen | Not specified | Not specified | Not specified | 1 | 0

F.Paste | Top solder paste | | Not specified | | 1 | 0

F.Mask | Top solder mask | Not specified | 0.01 mm | Not specified | 3.3 | 0

F.Cu | Copper | | 0.035 mm | | 1 | 0

Dielectric 1 | Prepreg | FR4 | 0.1 mm | Not specified | 4 | 0.02

In1.Cu | Copper | | 0.035 mm | | 1 | 0

Dielectric 2 | Core | FR4 | 0.535 mm | Not specified | 4.5 | 0.02

In2.Cu | Copper | | 0.035 mm | | 1 | 0

Dielectric 3 | Prepreg | FR4 | 0.1 mm | Not specified | 4 | 0.02

In3.Cu | Copper | | 0.035 mm | | 1 | 0

Dielectric 4 | Core | FR4 | 0.535 mm | Not specified | 4.5 | 0.02

In4.Cu | Copper | | 0.035 mm | | 1 | 0

Dielectric 5 | Prepreg | FR4 | 0.1 mm | Not specified | 4 | 0.02

B.Cu | Copper | | 0.035 mm | | 1 | 0

B.Mask | Bottom solder mask | Not specified | 0.01 mm | Not specified | 3.3 | 0

B.Paste | Bottom solder paste | | Not specified | | 1 | 0

B.Silkscreen | Bottom silk screen | Not specified | Not specified | Not specified | 1 | 0

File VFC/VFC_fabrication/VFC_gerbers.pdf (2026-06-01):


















C23 SM03B-SRSS-TB_LF__SN_ C15 C16 U9 C44 R15 C5 C13 SM03B-SRSS-TB_LF__SN_ C19 C42 C14 R30 SM04B-SRSS-TB_LF__SN_ SM03B-SRSS-TB_LF__SN_ C10


Layer Name | Type | Material | Thickness | Color | Epsilon R | Loss Tangent

F.Silkscreen | Top silk screen | Not specified | Not specified | Not specified | 1 | 0

F.Paste | Top solder paste | | Not specified | | 1 | 0

F.Mask | Top solder mask | Not specified | 0.01 mm | Not specified | 3.3 | 0

F.Cu | Copper | | 0.035 mm | | 1 | 0

Dielectric 1 | Prepreg | FR4 | 0.1 mm | Not specified | 4 | 0.02

In1.Cu | Copper | | 0.035 mm | | 1 | 0

Dielectric 2 | Core | FR4 | 0.535 mm | Not specified | 4.5 | 0.02

In2.Cu | Copper | | 0.035 mm | | 1 | 0

Dielectric 3 | Prepreg | FR4 | 0.1 mm | Not specified | 4 | 0.02

In3.Cu | Copper | | 0.035 mm | | 1 | 0

Dielectric 4 | Core | FR4 | 0.535 mm | Not specified | 4.5 | 0.02

In4.Cu | Copper | | 0.035 mm | | 1 | 0

Dielectric 5 | Prepreg | FR4 | 0.1 mm | Not specified | 4 | 0.02

B.Cu | Copper | | 0.035 mm | | 1 | 0

B.Mask | Bottom solder mask | Not specified | 0.01 mm | Not specified | 3.3 | 0

B.Paste | Bottom solder paste | | Not specified | | 1 | 0

B.Silkscreen | Bottom silk screen | Not specified | Not specified | Not specified | 1 | 0











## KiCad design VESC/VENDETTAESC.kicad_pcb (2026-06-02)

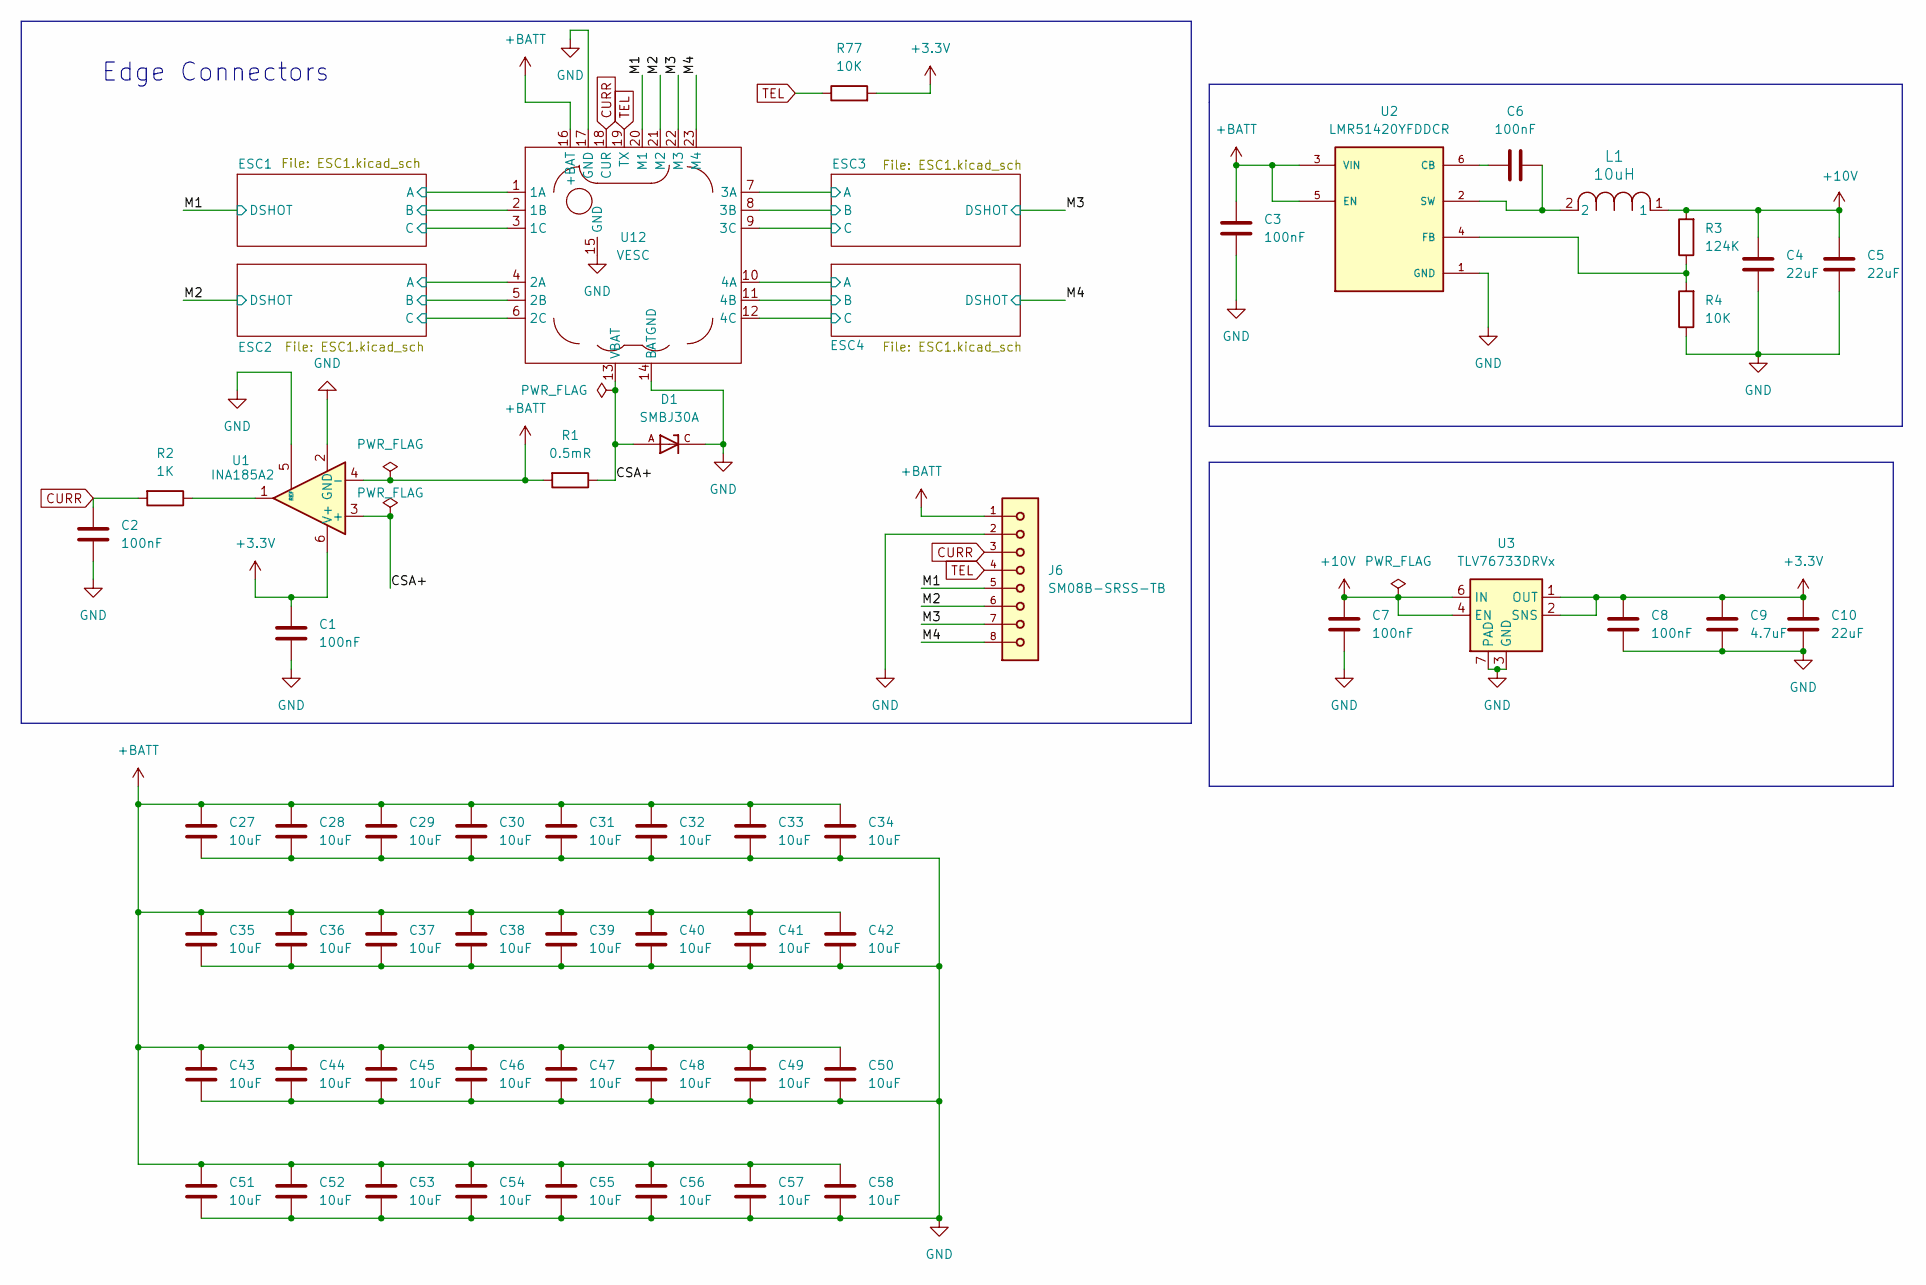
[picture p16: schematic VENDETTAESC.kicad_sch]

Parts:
C1, C2, C3, C6, C7, C8: 100nF; C_0402_1005Metric; Manufacturer Part Number GRM155R71H104KE14D; LCSC C77020
C4, C5, C10: 22uF; C_0805_2012Metric; Manufacturer Part Number CL21A226MAYNNNE; LCSC C602037
C9: 4.7uF; C_0603_1608Metric; Manufacturer Part Number CL10A475KO8NNNC; LCSC C19666
C27, C28, C29, C30, C31, C32, C33, C34, C35, C36, C37, C38, C39, C40, C41, C42, C43, C44, C45, C46, C47, C48, C49, C50, C51, C52, C53, C54, C55, C56, C57, C58: 10uF; C_0805_2012Metric; Manufacturer Part Number CL21A106KBYQNNE; LCSC C2932476
D1: SMBJ30A; DIOM4336X265N; PARTREV F2102; LCSC C135065
J6: SM08B-SRSS-TB; JST_SH_SM08B-SRSS-TB_1x08-1MP_P1.00mm_Horizontal; Manufacturer Part Number SM08B-SRSS-TB(LF)(SN); LCSC C160407
L1: 10uH; L_Changjiang_FTC404020S; Manufacturer Part Number GXTC0420-100-MT; LCSC C53198553
R1: 0.5mR; R_2512_6332Metric; Manufacturer Part Number EBWM2512JL500S9; LCSC C19679480
R2: 1K; R_0402_1005Metric; Manufacturer Part Number RC0402FR-071KL; LCSC C106235
R3: 124K; R_0402_1005Metric; Manufacturer Part Number 0402WGF1243TCE; LCSC C36777
R4, R77: 10K; R_0402_1005Metric; Manufacturer Part Number RC0402JR-0710KL; LCSC C60489
U1: INA185A2; SOT-563; Manufacturer Part Number INA185A2IDRLR; LCSC C2059320
U2: LMR51420YFDDCR; SOT95P280X110-6N; PARTREV C; LCSC C7296200
U3: TLV76733DRVx; WSON-6-1EP_2x2mm_P0.65mm_EP1x1.6mm_ThermalVias; Manufacturer Part Number TLV76733DRVR; LCSC C2848334
U12: VESC

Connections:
+3.3V: C1.1, C8.1, C9.1, C10.1, R77.2, U1.6 (V+), U3.1 (OUT), U3.2 (SNS); also elsewhere on the board
+10V: C4.1, C5.1, C7.1, L1.1, R3.2, U3.4 (EN), U3.6 (IN); also elsewhere on the board
+BATT: C3.1, C27.1, C28.1, C29.1, C30.1, C31.1, C32.1, C33.1, C34.1, C35.1, C36.1, C37.1, C38.1, C39.1, C40.1, C41.1, C42.1, C43.1, C44.1, C45.1, C46.1, C47.1, C48.1, C49.1, C50.1, C51.1, C52.1, C53.1, C54.1, C55.1, C56.1, C57.1, C58.1, J6.1, R1.2, U1.4 (-), U2.3 (VIN), U2.5 (EN), U12.16 (+BAT); also elsewhere on the board
/CSA+: D1.A, R1.1, U1.3 (+), U12.13 (VBAT)
/ESC1/MOTORA: U12.1 (1A); also elsewhere on the board
/ESC1/MOTORB: U12.2 (1B); also elsewhere on the board
/ESC1/MOTORC: U12.3 (1C); also elsewhere on the board
/ESC2/MOTORA: U12.4 (2A); also elsewhere on the board
/ESC2/MOTORB: U12.5 (2B); also elsewhere on the board
/ESC2/MOTORC: U12.6 (2C); also elsewhere on the board
/ESC3/MOTORA: U12.7 (3A); also elsewhere on the board
/ESC3/MOTORB: U12.8 (3B); also elsewhere on the board
/ESC3/MOTORC: U12.9 (3C); also elsewhere on the board
/ESC4/MOTORA: U12.10 (4A); also elsewhere on the board
/ESC4/MOTORB: U12.11 (4B); also elsewhere on the board
/ESC4/MOTORC: U12.12 (4C); also elsewhere on the board
/M1: J6.5, U12.20 (M1); also elsewhere on the board
/M2: J6.6, U12.21 (M2); also elsewhere on the board
/M3: J6.7, U12.22 (M3); also elsewhere on the board
/M4: J6.8, U12.23 (M4); also elsewhere on the board
CURR: C2.1, J6.3, R2.2, U12.18 (CUR)
GND: C1.2, C2.2, C3.2, C4.2, C5.2, C7.2, C8.2, C9.2, C10.2, C27.2, C28.2, C29.2, C30.2, C31.2, C32.2, C33.2, C34.2, C35.2, C36.2, C37.2, C38.2, C39.2, C40.2, C41.2, C42.2, C43.2, C44.2, C45.2, C46.2, C47.2, C48.2, C49.2, C50.2, C51.2, C52.2, C53.2, C54.2, C55.2, C56.2, C57.2, C58.2, D1.C, J6.2, R4.1, U1.2 (GND), U1.5 (REF), U2.1 (GND), U3.3 (GND), U3.5 (GND), U3.7 (PAD), U12.14 (BATGND), U12.15 (GND), U12.17 (GND); also elsewhere on the board
unnamed: R2.1, U1.1
unnamed: C6.2, U2.6 (CB)
unnamed: R3.1, R4.2, U2.4 (FB)
unnamed: C6.1, L1.2, U2.2 (SW)
TEL: J6.4, R77.1, U12.19 (TX); also elsewhere on the board

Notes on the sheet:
Edge Connectors

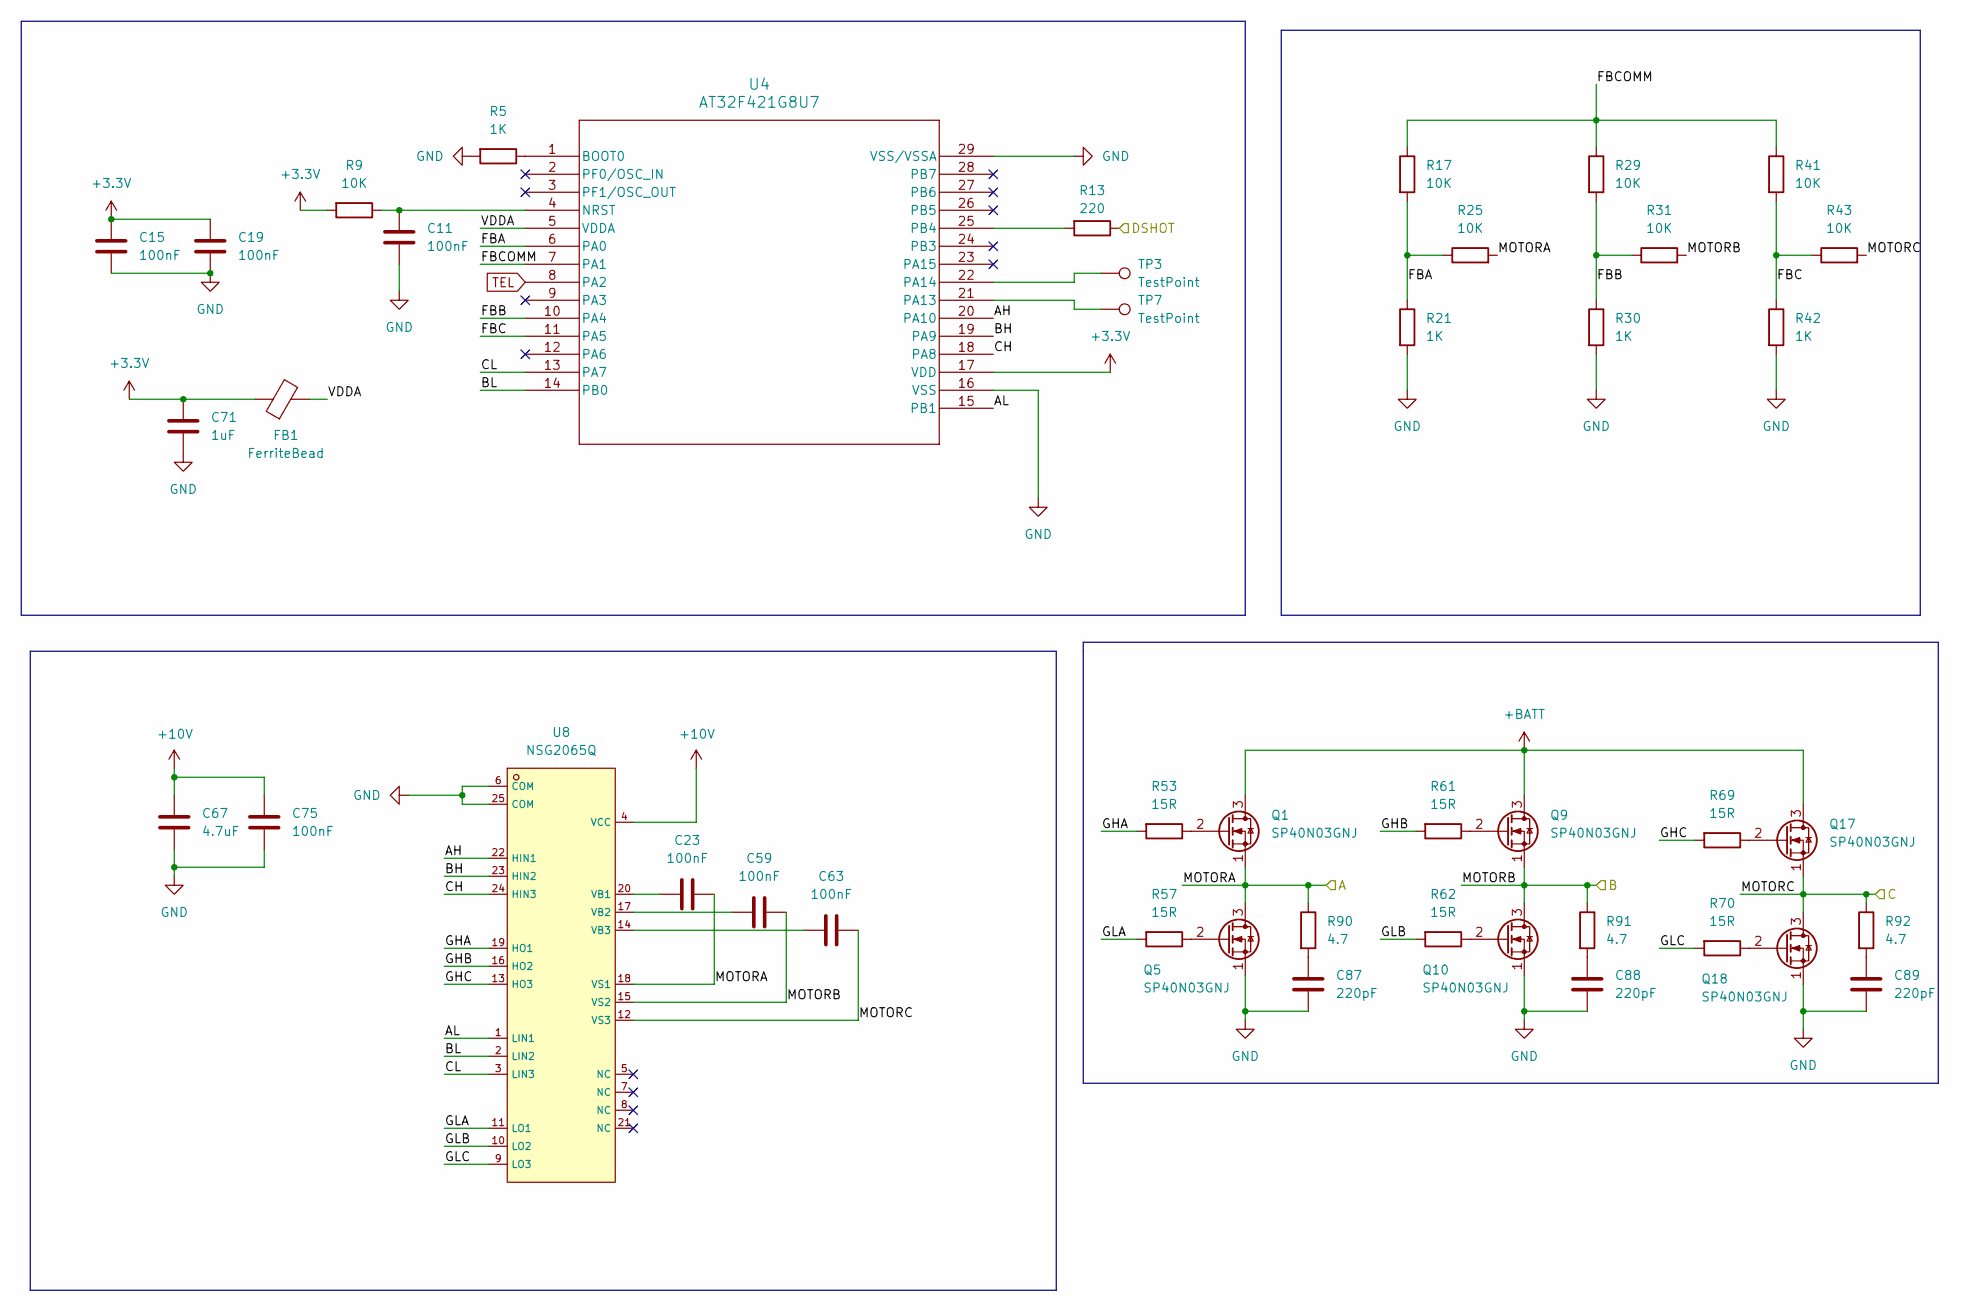
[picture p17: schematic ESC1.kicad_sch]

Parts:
C11, C15, C19, C23, C59, C63, C75: 100nF; C_0402_1005Metric; Manufacturer Part Number GRM155R71H104KE14D; LCSC C77020
C67: 4.7uF; C_0603_1608Metric; Manufacturer Part Number CL10A475KO8NNNC; LCSC C19666
C71: 1uF; C_0402_1005Metric; Manufacturer Part Number CL05A105KO5NNNC; LCSC C29266
C87, C88, C89: 220pF; C_0402_1005Metric; Manufacturer Part Number AC0402KRX7R0BB221; LCSC C7209937
FB1: FerriteBead; L_0402_1005Metric; Manufacturer Part Number CBW100505U101T; LCSC C124089
Q1, Q5, Q9, Q10, Q17, Q18: SP40N03GNJ; POWERPAK-1212-8_L3.0-W3.0-P0.65-LS3.3-BL; Manufacturer Part Number SP40N03GNJ; LCSC C22466709
R5, R21, R30, R42: 1K; R_0402_1005Metric; Manufacturer Part Number RC0402FR-071KL; LCSC C106235
R9, R17, R25, R29, R31, R41, R43: 10K; R_0402_1005Metric; Manufacturer Part Number RC0402JR-0710KL; LCSC C60489
R13: 220; R_0402_1005Metric; Manufacturer Part Number 0402WGJ0220TCE; LCSC C25152
R53, R57, R61, R62, R69, R70: 15R; R_0402_1005Metric; Manufacturer Part Number 0402WGF150JTCE; LCSC C25083
R90, R91, R92: 4.7; R_0402_1005Metric; Manufacturer Part Number 0402WGJ047JTCE; LCSC C25169
TP3, TP7: TestPoint; TestPoint_Pad_D1.0mm
U4: AT32F421G8U7; QFN28_4x4_ART; Manufacturer Part Number AT32F421G8U7; LCSC C2765098
U8: NSG2065Q; QFN-24_L4.0-W4.0-P0.50-TL-EP2.8; Manufacturer Part Number NSG2065Q; LCSC C41414478

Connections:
+3.3V: C15.1, C19.1, C71.1, FB1.1, R9.2, U4.17 (VDD); also elsewhere on the board
+10V: C67.1, C75.1, U8.4 (VCC); also elsewhere on the board
+BATT: Q1.3 (D), Q9.3 (D), Q17.3 (D); also elsewhere on the board
/ESC1/AH: U4.20 (PA10), U8.22 (HIN1)
/ESC1/AL: U4.15 (PB1), U8.1 (LIN1)
/ESC1/BH: U4.19 (PA9), U8.23 (HIN2)
/ESC1/BL: U4.14 (PB0), U8.2 (LIN2)
/ESC1/CH: U4.18 (PA8), U8.24 (HIN3)
/ESC1/CL: U4.13 (PA7), U8.3 (LIN3)
/ESC1/FBA: R17.2, R21.1, R25.1, U4.6 (PA0)
/ESC1/FBB: R29.2, R30.1, R31.1, U4.10 (PA4)
/ESC1/FBC: R41.2, R42.1, R43.1, U4.11 (PA5)
/ESC1/FBCOMM: R17.1, R29.1, R41.1, U4.7 (PA1)
/ESC1/GHA: R53.2, U8.19 (HO1)
/ESC1/GHB: R61.2, U8.16 (HO2)
/ESC1/GHC: R69.2, U8.13 (HO3)
/ESC1/GLA: R57.2, U8.11 (LO1)
/ESC1/GLB: R62.2, U8.10 (LO2)
/ESC1/GLC: R70.2, U8.9 (LO3)
/ESC1/MOTORA: C23.1, Q1.1 (S), Q5.3 (D), R25.2, R90.1, U8.18 (VS1); also elsewhere on the board
/ESC1/MOTORB: C59.1, Q9.1 (S), Q10.3 (D), R31.2, R91.1, U8.15 (VS2); also elsewhere on the board
/ESC1/MOTORC: C63.1, Q17.1 (S), Q18.3 (D), R43.2, R92.1, U8.12 (VS3); also elsewhere on the board
/ESC1/VDDA: FB1.2, U4.5 (VDDA)
/M1: R13.1; also elsewhere on the board
GND: C11.2, C15.2, C19.2, C67.2, C71.2, C75.2, C87.2, C88.2, C89.2, Q5.1 (S), Q10.1 (S), Q18.1 (S), R5.2, R21.2, R30.2, R42.2, U4.16 (VSS), U4.29 (VSS/VSSA), U8.6 (COM), U8.25 (COM); also elsewhere on the board
unnamed: C87.1, R90.2
unnamed: C88.1, R91.2
unnamed: C89.1, R92.2
unnamed: Q1.2 (G), R53.1
unnamed: Q5.2 (G), R57.1
unnamed: Q9.2 (G), R61.1
unnamed: Q10.2 (G), R62.1
unnamed: Q17.2 (G), R69.1
unnamed: Q18.2 (G), R70.1
unnamed: R5.1, U4.1 (BOOT0)
unnamed: C11.1, R9.1, U4.4 (NRST)
unnamed: TP7.1 (1_1), U4.21 (PA13)
unnamed: TP3.1 (1_1), U4.22 (PA14)
unnamed: R13.2, U4.25 (PB4)
unnamed: C23.2, U8.20 (VB1)
unnamed: C59.2, U8.17 (VB2)
unnamed: C63.2, U8.14 (VB3)
TEL: U4.8 (PA2); also elsewhere on the board

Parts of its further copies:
C12, C13, C14, C16, C17, C18, C20, C21, C22, C24, C25, C26, C60, C61, C62, C64, C65, C66, C76, C77, C78: 100nF; C_0402_1005Metric; Manufacturer Part Number GRM155R71H104KE14D; LCSC C77020
C68, C69, C70: 4.7uF; C_0603_1608Metric; Manufacturer Part Number CL10A475KO8NNNC; LCSC C19666
C72, C73, C74: 1uF; C_0402_1005Metric; Manufacturer Part Number CL05A105KO5NNNC; LCSC C29266
C90, C91, C92, C93, C94, C95, C96, C97, C98: 220pF; C_0402_1005Metric; Manufacturer Part Number AC0402KRX7R0BB221; LCSC C7209937
FB2, FB3, FB4: FerriteBead; L_0402_1005Metric; Manufacturer Part Number CBW100505U101T; LCSC C124089
Q2, Q3, Q4, Q6, Q7, Q8, Q11, Q12, Q13, Q14, Q15, Q16, Q19, Q20, Q21, Q22, Q23, Q24: SP40N03GNJ; POWERPAK-1212-8_L3.0-W3.0-P0.65-LS3.3-BL; Manufacturer Part Number SP40N03GNJ; LCSC C22466709
R6, R7, R8, R22, R23, R24, R33, R36, R39, R45, R48, R51: 1K; R_0402_1005Metric; Manufacturer Part Number RC0402FR-071KL; LCSC C106235
R10, R11, R12, R18, R19, R20, R26, R27, R28, R32, R34, R35, R37, R38, R40, R44, R46, R47, R49, R50, R52: 10K; R_0402_1005Metric; Manufacturer Part Number RC0402JR-0710KL; LCSC C60489
R14, R15, R16: 220; R_0402_1005Metric; Manufacturer Part Number 0402WGJ0220TCE; LCSC C25152
R54, R55, R56, R58, R59, R60, R63, R64, R65, R66, R67, R68, R71, R72, R73, R74, R75, R76: 15R; R_0402_1005Metric; Manufacturer Part Number 0402WGF150JTCE; LCSC C25083
R93, R94, R95, R96, R97, R98, R99, R100, R101: 4.7; R_0402_1005Metric; Manufacturer Part Number 0402WGJ047JTCE; LCSC C25169
TP4, TP5, TP6, TP8, TP9, TP10: TestPoint; TestPoint_Pad_D1.0mm
U5, U6, U7: AT32F421G8U7; QFN28_4x4_ART; Manufacturer Part Number AT32F421G8U7; LCSC C2765098
U9, U10, U11: NSG2065Q; QFN-24_L4.0-W4.0-P0.50-TL-EP2.8; Manufacturer Part Number NSG2065Q; LCSC C41414478

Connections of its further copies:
+3.3V: C16.1, C17.1, C18.1, C20.1, C21.1, C22.1, C72.1, C73.1, C74.1, FB2.1, FB3.1, FB4.1, R10.2, R11.2, R12.2, U5.17 (VDD), U6.17 (VDD), U7.17 (VDD); also elsewhere on the board
+10V: C68.1, C69.1, C70.1, C76.1, C77.1, C78.1, U9.4 (VCC), U10.4 (VCC), U11.4 (VCC); also elsewhere on the board
+BATT: Q2.3 (D), Q3.3 (D), Q4.3 (D), Q11.3 (D), Q13.3 (D), Q15.3 (D), Q19.3 (D), Q21.3 (D), Q23.3 (D); also elsewhere on the board
/ESC2/AH: U5.20 (PA10), U9.22 (HIN1)
/ESC2/AL: U5.15 (PB1), U9.1 (LIN1)
/ESC2/BH: U5.19 (PA9), U9.23 (HIN2)
/ESC2/BL: U5.14 (PB0), U9.2 (LIN2)
/ESC2/CH: U5.18 (PA8), U9.24 (HIN3)
/ESC2/CL: U5.13 (PA7), U9.3 (LIN3)
/ESC2/FBA: R18.2, R22.1, R26.1, U5.6 (PA0)
/ESC2/FBB: R32.2, R33.1, R34.1, U5.10 (PA4)
/ESC2/FBC: R44.2, R45.1, R46.1, U5.11 (PA5)
/ESC2/FBCOMM: R18.1, R32.1, R44.1, U5.7 (PA1)
/ESC2/GHA: R54.2, U9.19 (HO1)
/ESC2/GHB: R63.2, U9.16 (HO2)
/ESC2/GHC: R71.2, U9.13 (HO3)
/ESC2/GLA: R58.2, U9.11 (LO1)
/ESC2/GLB: R64.2, U9.10 (LO2)
/ESC2/GLC: R72.2, U9.9 (LO3)
/ESC2/MOTORA: C24.1, Q2.1 (S), Q6.3 (D), R26.2, R93.1, U9.18 (VS1); also elsewhere on the board
/ESC2/MOTORB: C60.1, Q11.1 (S), Q12.3 (D), R34.2, R94.1, U9.15 (VS2); also elsewhere on the board
/ESC2/MOTORC: C64.1, Q19.1 (S), Q20.3 (D), R46.2, R95.1, U9.12 (VS3); also elsewhere on the board
/ESC2/VDDA: FB2.2, U5.5 (VDDA)
/ESC3/AH: U6.20 (PA10), U10.22 (HIN1)
/ESC3/AL: U6.15 (PB1), U10.1 (LIN1)
/ESC3/BH: U6.19 (PA9), U10.23 (HIN2)
/ESC3/BL: U6.14 (PB0), U10.2 (LIN2)
/ESC3/CH: U6.18 (PA8), U10.24 (HIN3)
/ESC3/CL: U6.13 (PA7), U10.3 (LIN3)
/ESC3/FBA: R19.2, R23.1, R27.1, U6.6 (PA0)
/ESC3/FBB: R35.2, R36.1, R37.1, U6.10 (PA4)
/ESC3/FBC: R47.2, R48.1, R49.1, U6.11 (PA5)
/ESC3/FBCOMM: R19.1, R35.1, R47.1, U6.7 (PA1)
/ESC3/GHA: R55.2, U10.19 (HO1)
/ESC3/GHB: R65.2, U10.16 (HO2)
/ESC3/GHC: R73.2, U10.13 (HO3)
/ESC3/GLA: R59.2, U10.11 (LO1)
/ESC3/GLB: R66.2, U10.10 (LO2)
/ESC3/GLC: R74.2, U10.9 (LO3)
/ESC3/MOTORA: C25.1, Q3.1 (S), Q7.3 (D), R27.2, R96.1, U10.18 (VS1); also elsewhere on the board
/ESC3/MOTORB: C61.1, Q13.1 (S), Q14.3 (D), R37.2, R97.1, U10.15 (VS2); also elsewhere on the board
/ESC3/MOTORC: C65.1, Q21.1 (S), Q22.3 (D), R49.2, R98.1, U10.12 (VS3); also elsewhere on the board
/ESC3/VDDA: FB3.2, U6.5 (VDDA)
/ESC4/AH: U7.20 (PA10), U11.22 (HIN1)
/ESC4/AL: U7.15 (PB1), U11.1 (LIN1)
/ESC4/BH: U7.19 (PA9), U11.23 (HIN2)
/ESC4/BL: U7.14 (PB0), U11.2 (LIN2)
/ESC4/CH: U7.18 (PA8), U11.24 (HIN3)
/ESC4/CL: U7.13 (PA7), U11.3 (LIN3)
/ESC4/FBA: R20.2, R24.1, R28.1, U7.6 (PA0)
/ESC4/FBB: R38.2, R39.1, R40.1, U7.10 (PA4)
/ESC4/FBC: R50.2, R51.1, R52.1, U7.11 (PA5)
/ESC4/FBCOMM: R20.1, R38.1, R50.1, U7.7 (PA1)
/ESC4/GHA: R56.2, U11.19 (HO1)
/ESC4/GHB: R67.2, U11.16 (HO2)
/ESC4/GHC: R75.2, U11.13 (HO3)
/ESC4/GLA: R60.2, U11.11 (LO1)
/ESC4/GLB: R68.2, U11.10 (LO2)
/ESC4/GLC: R76.2, U11.9 (LO3)
/ESC4/MOTORA: C26.1, Q4.1 (S), Q8.3 (D), R28.2, R99.1, U11.18 (VS1); also elsewhere on the board
/ESC4/MOTORB: C62.1, Q15.1 (S), Q16.3 (D), R40.2, R100.1, U11.15 (VS2); also elsewhere on the board
/ESC4/MOTORC: C66.1, Q23.1 (S), Q24.3 (D), R52.2, R101.1, U11.12 (VS3); also elsewhere on the board
/ESC4/VDDA: FB4.2, U7.5 (VDDA)
/M2: R14.1; also elsewhere on the board
/M3: R15.1; also elsewhere on the board
/M4: R16.1; also elsewhere on the board
GND: C12.2, C13.2, C14.2, C16.2, C17.2, C18.2, C20.2, C21.2, C22.2, C68.2, C69.2, C70.2, C72.2, C73.2, C74.2, C76.2, C77.2, C78.2, C90.2, C91.2, C92.2, C93.2, C94.2, C95.2, C96.2, C97.2, C98.2, Q6.1 (S), Q7.1 (S), Q8.1 (S), Q12.1 (S), Q14.1 (S), Q16.1 (S), Q20.1 (S), Q22.1 (S), Q24.1 (S), R6.2, R7.2, R8.2, R22.2, R23.2, R24.2, R33.2, R36.2, R39.2, R45.2, R48.2, R51.2, U5.16 (VSS), U5.29 (VSS/VSSA), U6.16 (VSS), U6.29 (VSS/VSSA), U7.16 (VSS), U7.29 (VSS/VSSA), U9.6 (COM), U9.25 (COM), U10.6 (COM), U10.25 (COM), U11.6 (COM), U11.25 (COM); also elsewhere on the board
unnamed: C90.1, R93.2
unnamed: C91.1, R94.2
unnamed: C92.1, R95.2
unnamed: C93.1, R96.2
unnamed: C94.1, R97.2
unnamed: C95.1, R98.2
unnamed: C96.1, R99.2
unnamed: C97.1, R100.2
unnamed: C98.1, R101.2
unnamed: Q2.2 (G), R54.1
unnamed: Q3.2 (G), R55.1
unnamed: Q4.2 (G), R56.1
unnamed: Q6.2 (G), R58.1
unnamed: Q7.2 (G), R59.1
unnamed: Q8.2 (G), R60.1
unnamed: Q11.2 (G), R63.1
unnamed: Q12.2 (G), R64.1
unnamed: Q13.2 (G), R65.1
unnamed: Q14.2 (G), R66.1
unnamed: Q15.2 (G), R67.1
unnamed: Q16.2 (G), R68.1
unnamed: Q19.2 (G), R71.1
unnamed: Q20.2 (G), R72.1
unnamed: Q21.2 (G), R73.1
unnamed: Q22.2 (G), R74.1
unnamed: Q23.2 (G), R75.1
unnamed: Q24.2 (G), R76.1
unnamed: R6.1, U5.1 (BOOT0)
unnamed: C12.1, R10.1, U5.4 (NRST)
unnamed: TP8.1 (1_1), U5.21 (PA13)
unnamed: TP4.1 (1_1), U5.22 (PA14)
unnamed: R14.2, U5.25 (PB4)
unnamed: R7.1, U6.1 (BOOT0)
unnamed: C13.1, R11.1, U6.4 (NRST)
unnamed: TP9.1 (1_1), U6.21 (PA13)
unnamed: TP5.1 (1_1), U6.22 (PA14)
unnamed: R15.2, U6.25 (PB4)
unnamed: R8.1, U7.1 (BOOT0)
unnamed: C14.1, R12.1, U7.4 (NRST)
unnamed: TP10.1 (1_1), U7.21 (PA13)
unnamed: TP6.1 (1_1), U7.22 (PA14)
unnamed: R16.2, U7.25 (PB4)
unnamed: C24.2, U9.20 (VB1)
unnamed: C60.2, U9.17 (VB2)
unnamed: C64.2, U9.14 (VB3)
unnamed: C25.2, U10.20 (VB1)
unnamed: C61.2, U10.17 (VB2)
unnamed: C65.2, U10.14 (VB3)
unnamed: C26.2, U11.20 (VB1)
unnamed: C62.2, U11.17 (VB2)
unnamed: C66.2, U11.14 (VB3)
TEL: U5.8 (PA2), U6.8 (PA2), U7.8 (PA2); also elsewhere on the board

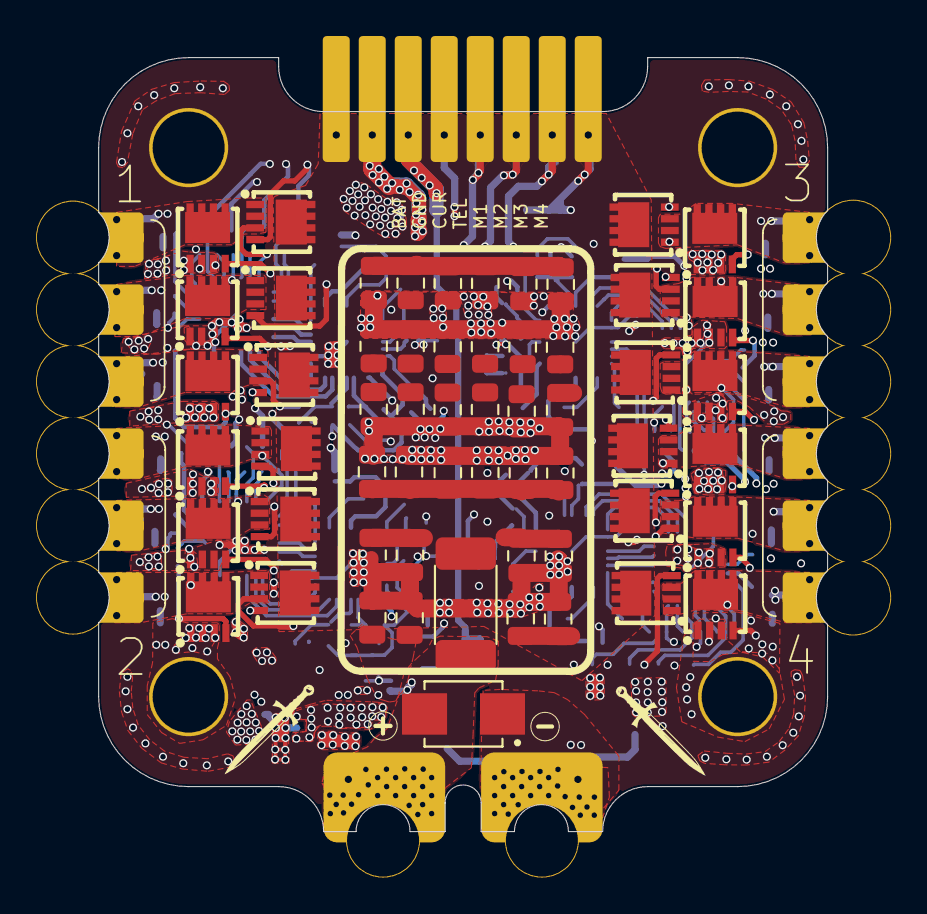
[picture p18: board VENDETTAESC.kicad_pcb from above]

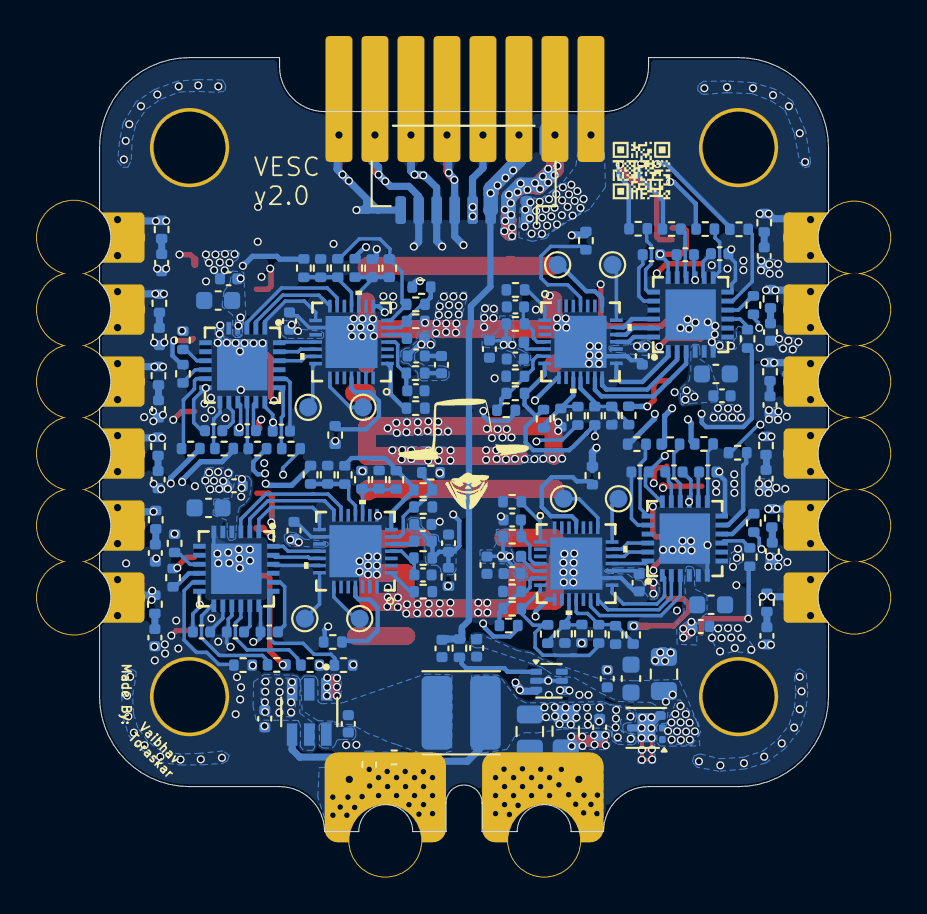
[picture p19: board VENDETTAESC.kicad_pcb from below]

Board: 6 copper layers, 40.5 x 43.0 mm, 235 parts (172 on the bottom side), 163 nets.

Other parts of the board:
knifelogo1, knifelogo2: LOGO; KNIFE_F
minus: LOGO; minus_f
plus: LOGO; plus_f
vlogo: LOGO; VLOGO

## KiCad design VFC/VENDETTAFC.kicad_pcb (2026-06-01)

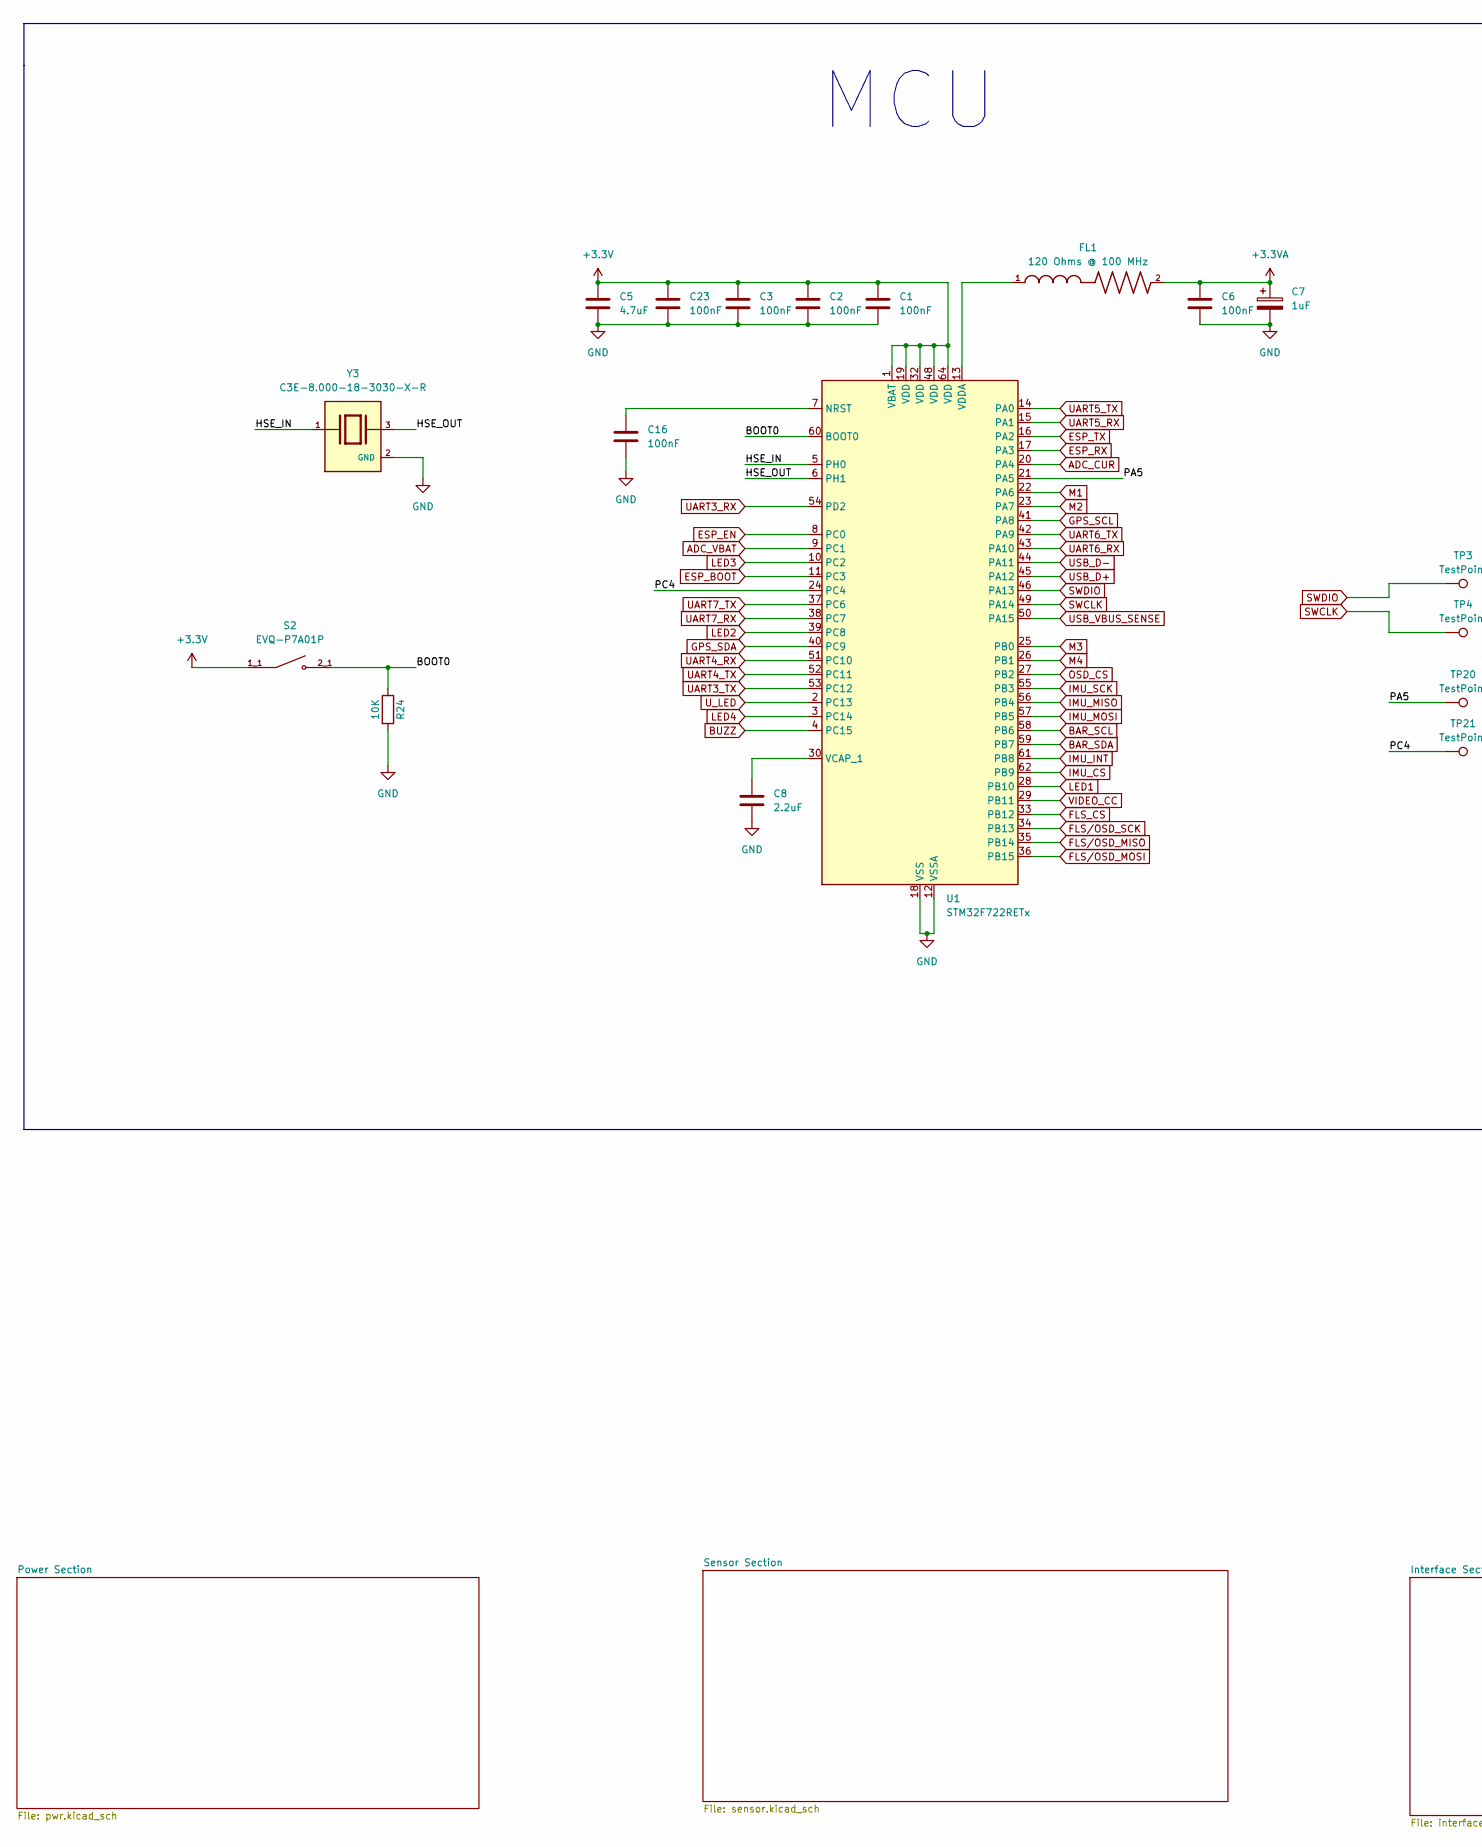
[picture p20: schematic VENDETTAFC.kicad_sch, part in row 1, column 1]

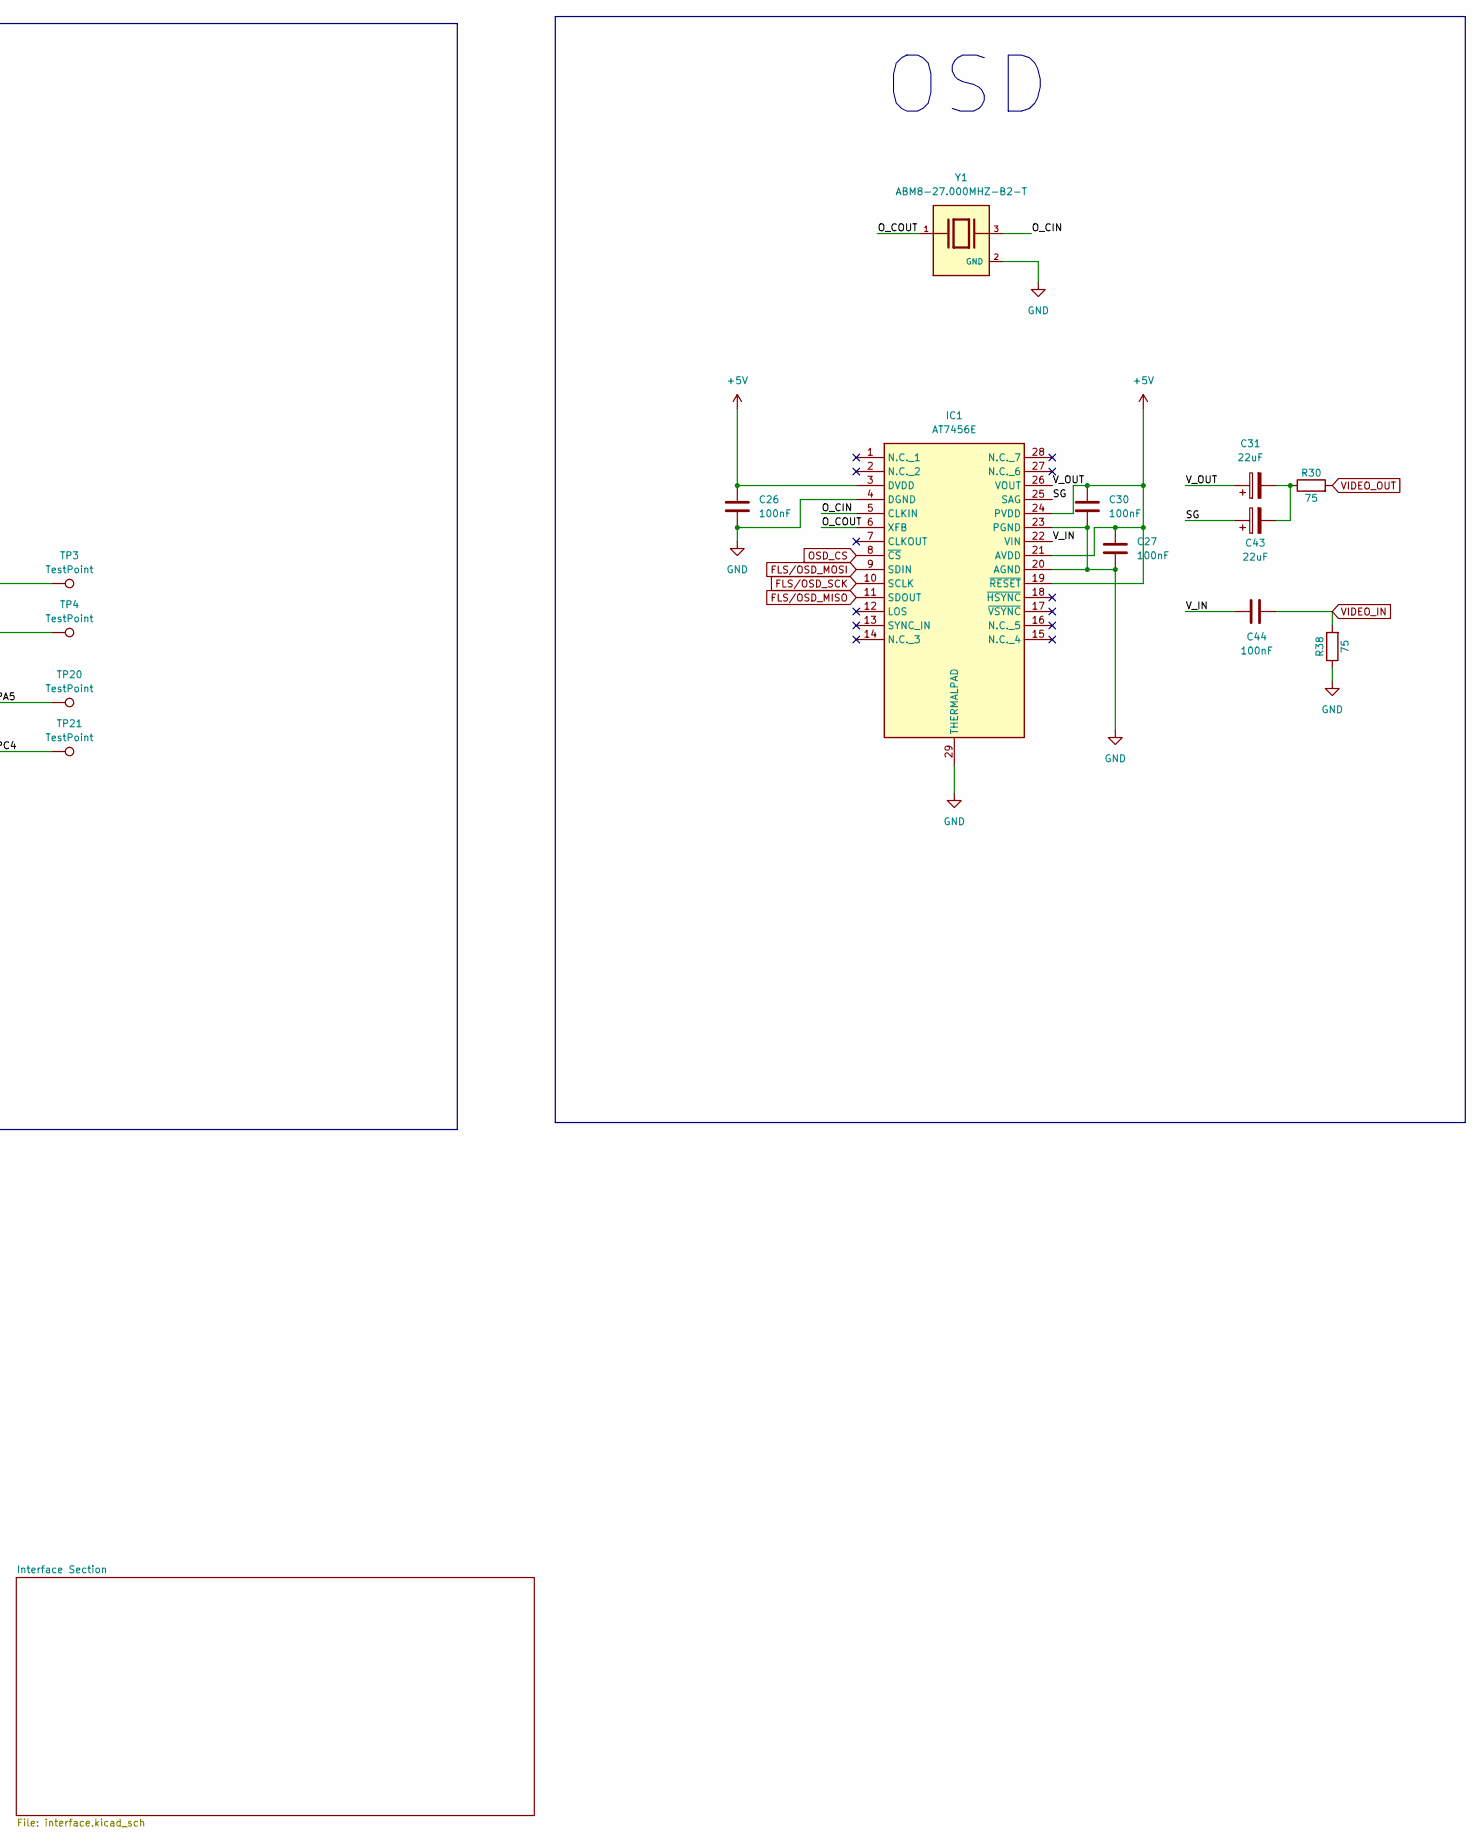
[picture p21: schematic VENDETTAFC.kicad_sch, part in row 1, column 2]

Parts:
C1, C2, C3, C6, C16, C23, C26, C27, C30, C44: 100nF; C_0402_1005Metric; MANUFACTURER PART NUMBER CL05A104KA5NNNC; LCSC C100072
C5: 4.7uF; C_0603_1608Metric; MANUFACTURER PART NUMBER CL10A475KO8NNNC; LCSC C19666
C7: 1uF; C_0805_2012Metric; MANUFACTURER PART NUMBER CL21B105KOFNNNE; LCSC C24123
C8: 2.2uF; C_0402_1005Metric; MANUFACTURER PART NUMBER CL05A225KP5NSNC; LCSC C107369
C31, C43: 22uF; C_0805_2012Metric; MANUFACTURER PART NUMBER HGC0805R5226M350NSLJ; LCSC C22367832
FL1: 120 Ohms @ 100 MHz; L_0402_1005Metric; MANUFACTURER PART NUMBER MPZ1005S121CT000; LCSC C107331
IC1: AT7456E; SOP65P640X120-29N; Manufacturer_Part_Number AT7456E; LCSC C82351
R24: 10K; R_0402_1005Metric; MANUFACTURER PART NUMBER RC0402JR-0710KL; LCSC C60489
R30, R38: 75; R_0402_1005Metric; MANUFACTURER PART NUMBER RC0402JR-0775RL; LCSC C137841
S2: EVQ-P7A01P; SW_EVQ-P7A01P; PARTREV 2022.4; LCSC C79167
TP3, TP4, TP20, TP21: TestPoint; TestPoint_Pad_D1.0mm
U1: STM32F722RETx; LQFP-64_10x10mm_P0.5mm; MANUFACTURER PART NUMBER STM32F722RET6; LCSC C118207
Y1: ABM8-27.000MHZ-B2-T; XTAL_ABM8-27.000MHZ-B2-T; PARTREV 44041; LCSC C1985251
Y3: C3E-8.000-18-3030-X-R; XTAL_C3E-8.000-18-3030-X-R; PARTREV August 01, 2022; LCSC C2682775

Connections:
+3.3V: C1.1, C2.1, C3.1, C5.1, C23.1, S2.1_1, S2.1_2, U1.1 (VBAT), U1.19 (VDD), U1.32 (VDD), U1.48 (VDD), U1.64 (VDD); also elsewhere on the board
+3.3VA: C6.1, C7.1, FL1.2; also elsewhere on the board
+5V: C26.1, C27.1, C30.1, IC1.3 (DVDD), IC1.19 (~RESET), IC1.21 (AVDD), IC1.24 (PVDD); also elsewhere on the board
/BOOT0: R24.1, S2.2_1, S2.2_2, U1.60 (BOOT0)
/HSE_IN: U1.5 (PH0), Y3.1
/HSE_OUT: U1.6 (PH1), Y3.3
/O_CIN: IC1.5 (CLKIN), Y1.3
/O_COUT: IC1.6 (XFB), Y1.1
/PA5: TP20.1 (1_1), U1.21 (PA5)
/PC4: TP21.1 (1_1), U1.24 (PC4)
/SG: C43.1, IC1.25 (SAG)
/V_IN: C44.1, IC1.22 (VIN)
/V_OUT: C31.1, IC1.26 (VOUT)
ADC_CUR: U1.20 (PA4); also elsewhere on the board
ADC_VBAT: U1.9 (PC1); also elsewhere on the board
BAR_SCL: U1.58 (PB6); also elsewhere on the board
BAR_SDA: U1.59 (PB7); also elsewhere on the board
BUZZ: U1.4 (PC15); also elsewhere on the board
ESP_BOOT: U1.11 (PC3); also elsewhere on the board
ESP_EN: U1.8 (PC0); also elsewhere on the board
ESP_RX: U1.17 (PA3); also elsewhere on the board
ESP_TX: U1.16 (PA2); also elsewhere on the board
FLS_CS: U1.33 (PB12); also elsewhere on the board
FLS/OSD_MISO: IC1.11 (SDOUT), U1.35 (PB14); also elsewhere on the board
FLS/OSD_MOSI: IC1.9 (SDIN), U1.36 (PB15); also elsewhere on the board
FLS/OSD_SCK: IC1.10 (SCLK), U1.34 (PB13); also elsewhere on the board
GND: C1.2, C2.2, C3.2, C5.2, C6.2, C7.2, C8.2, C16.2, C23.2, C26.2, C27.2, C30.2, IC1.4 (DGND), IC1.20 (AGND), IC1.23 (PGND), IC1.29 (THERMALPAD), R24.2, R38.1, U1.12 (VSSA), U1.18 (VSS), U1.31 (VSS), U1.47 (VSS), U1.63 (VSS), Y1.2 (GND), Y1.4 (GND), Y3.2 (GND), Y3.4 (GND); also elsewhere on the board
GPS_SCL: U1.41 (PA8); also elsewhere on the board
GPS_SDA: U1.40 (PC9); also elsewhere on the board
IMU_CS: U1.62 (PB9); also elsewhere on the board
IMU_INT: U1.61 (PB8); also elsewhere on the board
IMU_MISO: U1.56 (PB4); also elsewhere on the board
IMU_MOSI: U1.57 (PB5); also elsewhere on the board
IMU_SCK: U1.55 (PB3); also elsewhere on the board
LED1: U1.28 (PB10); also elsewhere on the board
LED2: U1.39 (PC8); also elsewhere on the board
LED3: U1.10 (PC2); also elsewhere on the board
LED4: U1.3 (PC14); also elsewhere on the board
M1: U1.22 (PA6); also elsewhere on the board
M2: U1.23 (PA7); also elsewhere on the board
M3: U1.25 (PB0); also elsewhere on the board
M4: U1.26 (PB1); also elsewhere on the board
unnamed: C31.2, C43.2, R30.1
unnamed: C16.1, U1.7 (NRST)
unnamed: C8.1, U1.30 (VCAP_1)
unnamed: FL1.1, U1.13 (VDDA)
OSD_CS: IC1.8 (~CS), U1.27 (PB2)
SWCLK: TP4.1 (1_1), U1.49 (PA14)
SWDIO: TP3.1 (1_1), U1.46 (PA13)
UART3_RX: U1.54 (PD2); also elsewhere on the board
UART3_TX: U1.53 (PC12); also elsewhere on the board
UART4_RX: U1.51 (PC10); also elsewhere on the board
UART4_TX: U1.52 (PC11); also elsewhere on the board
UART5_RX: U1.15 (PA1); also elsewhere on the board
UART5_TX: U1.14 (PA0); also elsewhere on the board
UART6_RX: U1.43 (PA10)
UART6_TX: U1.42 (PA9)
UART7_RX: U1.38 (PC7); also elsewhere on the board
UART7_TX: U1.37 (PC6); also elsewhere on the board
USB_D+: U1.45 (PA12); also elsewhere on the board
USB_D-: U1.44 (PA11); also elsewhere on the board
USB_VBUS_SENSE: U1.50 (PA15); also elsewhere on the board
U_LED: U1.2 (PC13); also elsewhere on the board
VIDEO_CC: U1.29 (PB11); also elsewhere on the board
VIDEO_IN: C44.2, R38.2; also elsewhere on the board
VIDEO_OUT: R30.2; also elsewhere on the board

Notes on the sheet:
MCU
OSD

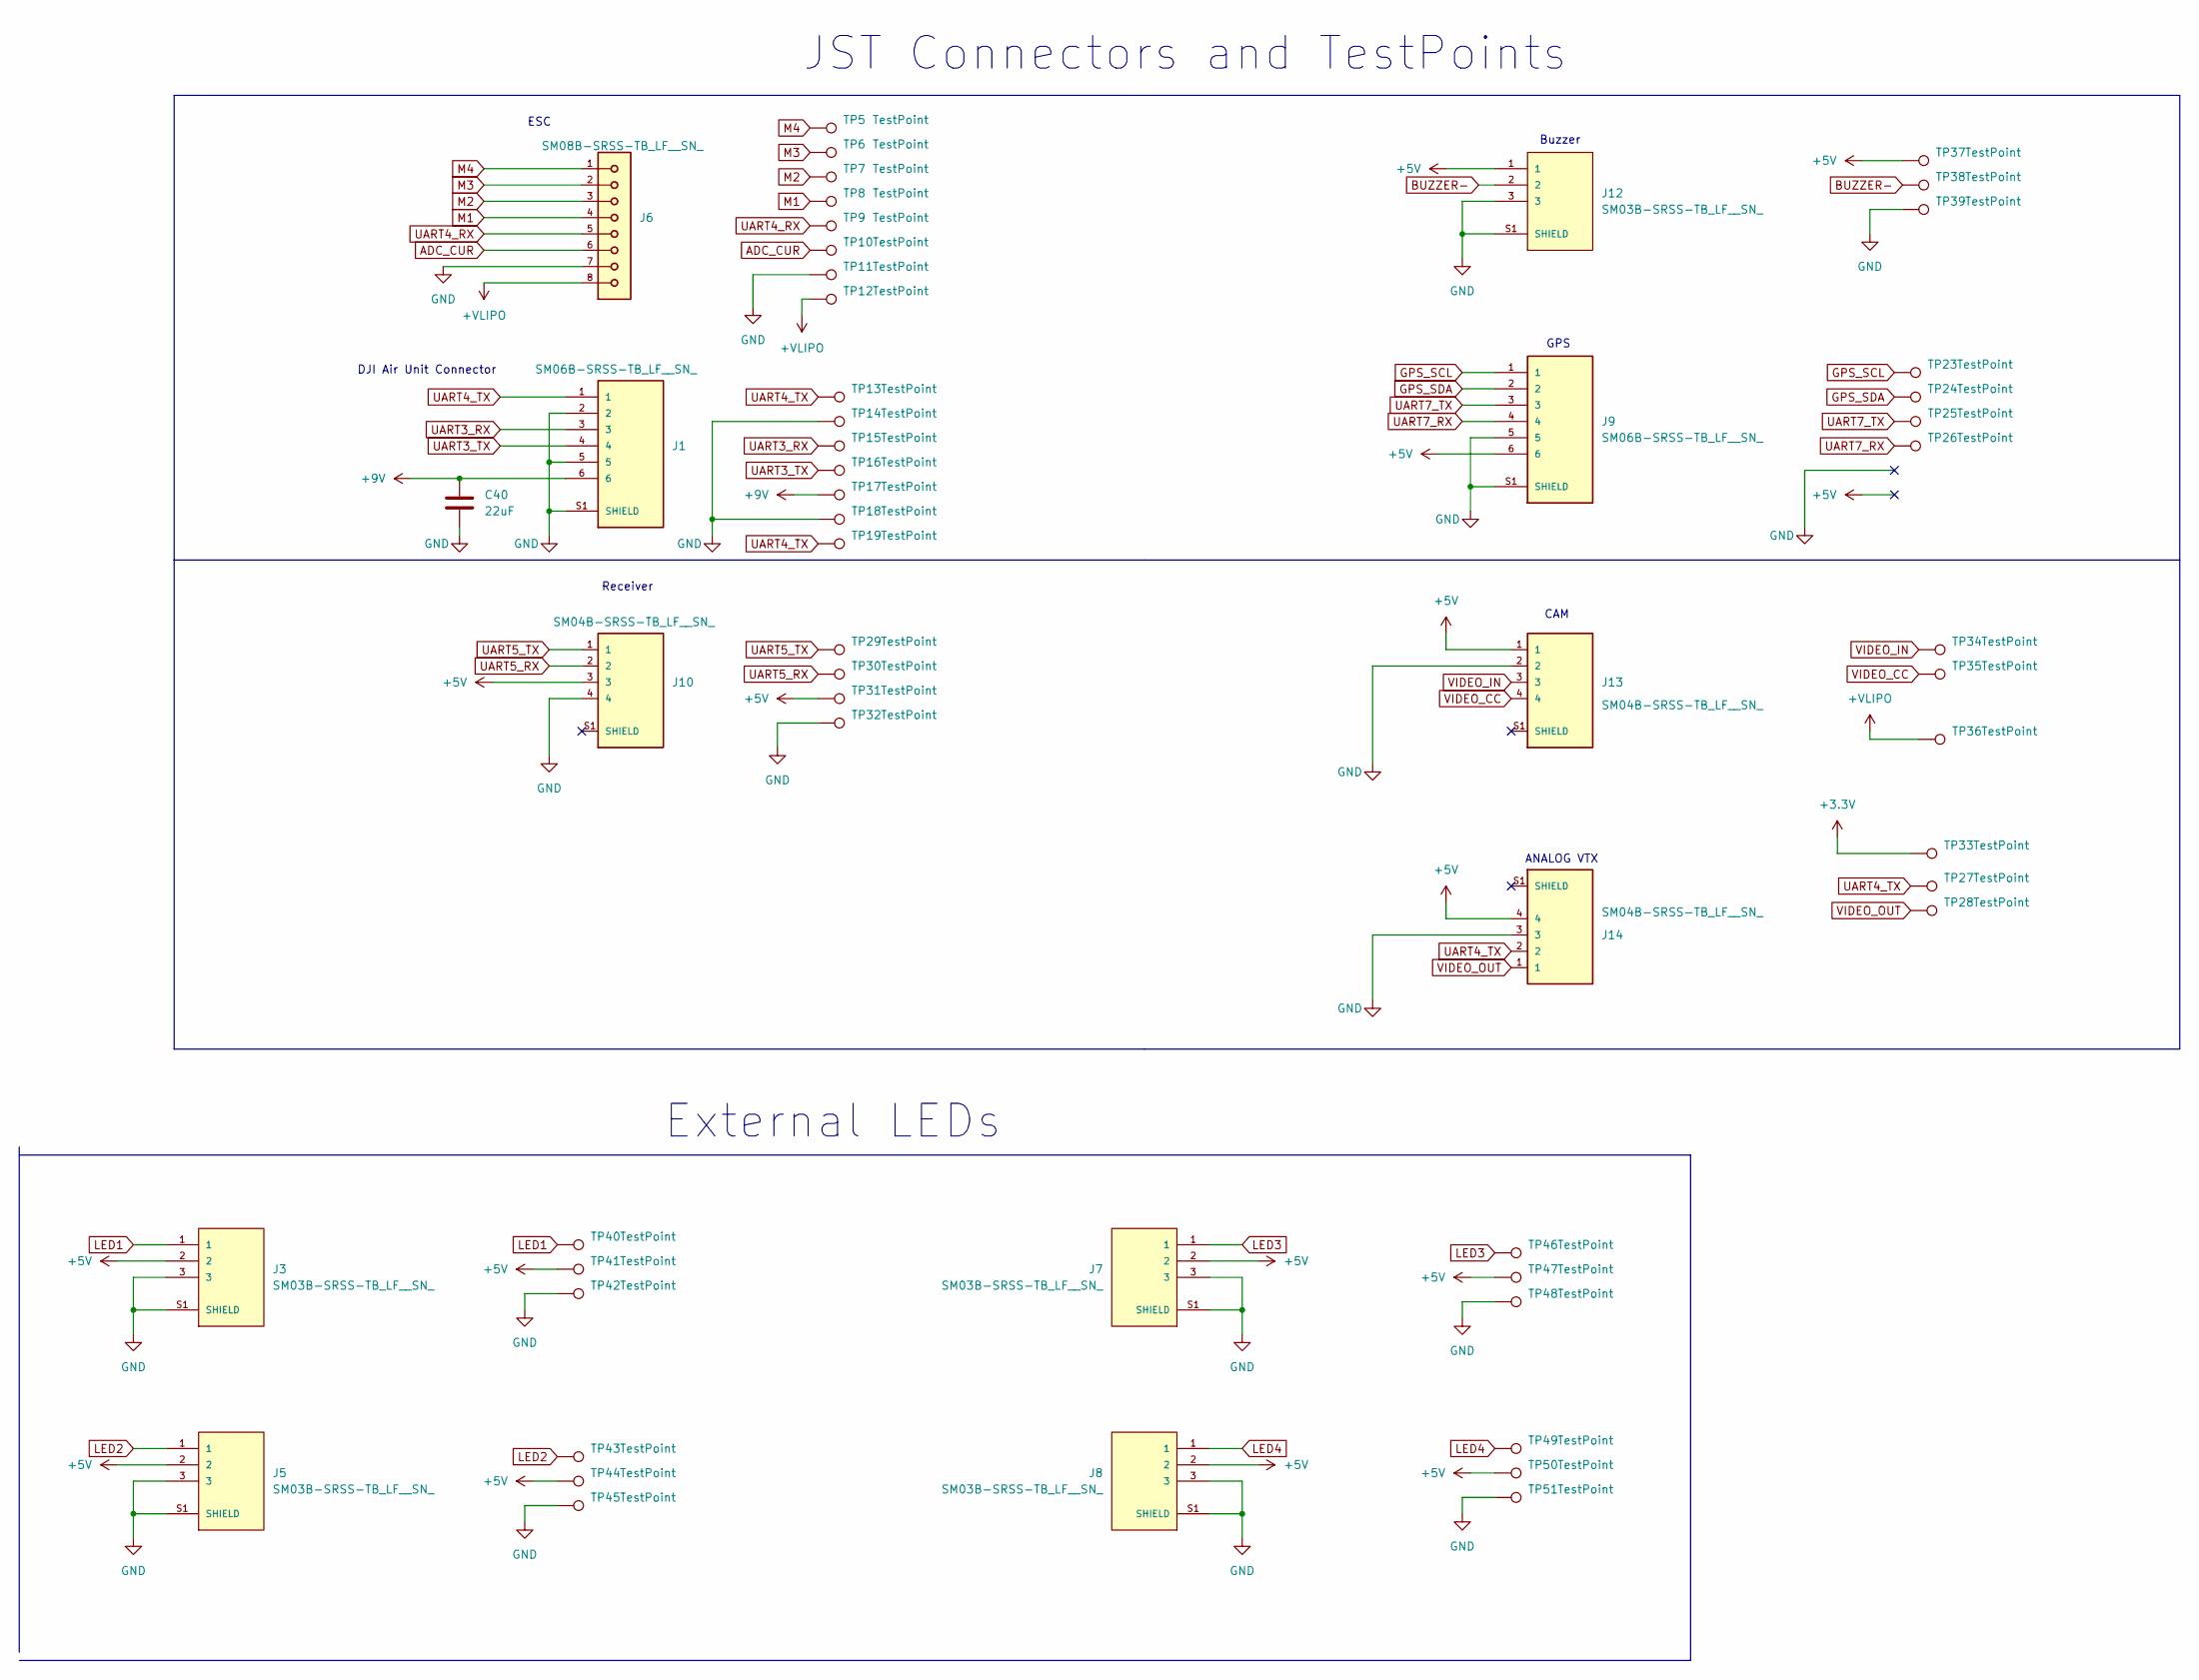
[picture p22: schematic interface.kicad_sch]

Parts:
C40: 22uF; C_0805_2012Metric; MANUFACTURER PART NUMBER HGC0805R5226M350NSLJ; LCSC C22367832
J1, J9: SM06B-SRSS-TB_LF__SN_; JST_SM06B-SRSS-TB_LF__SN_; MANUFACTURER PART NUMBER HC-1.0-6PWT; LCSC C2845365
J3, J5, J7, J8, J12: SM03B-SRSS-TB_LF__SN_; JST_SM03B-SRSS-TB_LF__SN_; MANUFACTURER PART NUMBER HC-1.0-3PWT; LCSC C2845362
J6: SM08B-SRSS-TB_LF__SN_; JST_SM08B-SRSS-TB_LF__SN_; MANUFACTURER PART NUMBER SM08B-SRSS-TB(LF)(SN); LCSC C160407
J10, J13, J14: SM04B-SRSS-TB_LF__SN_; JST_SM04B-SRSS-TB_LF__SN_; MANUFACTURER PART NUMBER HC-1.0-4PWT; LCSC C2845363
TP5, TP6, TP7, TP8, TP9, TP10, TP40, TP41, TP42, TP43, TP44, TP45, TP46, TP47, TP48, TP49, TP50, TP51: TestPoint; TestPoint_Pad_D1.0mm
TP11, TP12: TestPoint; TestPoint_Pad_D2.0mm
TP13, TP14, TP15, TP16, TP18, TP19, TP23, TP24, TP25, TP26, TP27, TP28, TP29, TP30, TP32, TP33, TP34, TP35, TP36, TP38, TP39: TestPoint; TestPoint_Pad_1.0x1.0mm
TP17, TP31, TP37: TestPoint; TestPoint_Pad_2.0x2.0mm

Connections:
+3.3V: TP33.1 (1_1); also elsewhere on the board
+5V: J3.2, J5.2, J7.2, J8.2, J9.6, J10.3, J12.1, J13.1, J14.4, TP31.1 (1_1), TP37.1 (1_1), TP41.1 (1_1), TP44.1 (1_1), TP47.1 (1_1), TP50.1 (1_1); also elsewhere on the board
+9V: C40.1, J1.6, TP17.1 (1_1); also elsewhere on the board
+VLIPO: J6.8, TP12.1 (1_1), TP36.1 (1_1); also elsewhere on the board
ADC_CUR: J6.6, TP10.1 (1_1); also elsewhere on the board
BUZZER-: J12.2, TP38.1 (1_1); also elsewhere on the board
GND: C40.2, J1.2, J1.5, J1.S1 (SHIELD), J1.S2 (SHIELD), J3.3, J3.S1 (SHIELD), J3.S2 (SHIELD), J5.3, J5.S1 (SHIELD), J5.S2 (SHIELD), J6.7, J7.3, J7.S1 (SHIELD), J7.S2 (SHIELD), J8.3, J8.S1 (SHIELD), J8.S2 (SHIELD), J9.5, J9.S1 (SHIELD), J9.S2 (SHIELD), J10.4, J12.3, J12.S1 (SHIELD), J12.S2 (SHIELD), J13.2, J14.3, TP11.1 (1_1), TP14.1 (1_1), TP18.1 (1_1), TP32.1 (1_1), TP39.1 (1_1), TP42.1 (1_1), TP45.1 (1_1), TP48.1 (1_1), TP51.1 (1_1); also elsewhere on the board
GPS_SCL: J9.1, TP23.1 (1_1); also elsewhere on the board
GPS_SDA: J9.2, TP24.1 (1_1); also elsewhere on the board
LED1: J3.1, TP40.1 (1_1); also elsewhere on the board
LED2: J5.1, TP43.1 (1_1); also elsewhere on the board
LED3: J7.1, TP46.1 (1_1); also elsewhere on the board
LED4: J8.1, TP49.1 (1_1); also elsewhere on the board
M1: J6.4, TP8.1 (1_1); also elsewhere on the board
M2: J6.3, TP7.1 (1_1); also elsewhere on the board
M3: J6.2, TP6.1 (1_1); also elsewhere on the board
M4: J6.1, TP5.1 (1_1); also elsewhere on the board
UART3_RX: J1.3, TP15.1 (1_1); also elsewhere on the board
UART3_TX: J1.4, TP16.1 (1_1); also elsewhere on the board
UART4_RX: J6.5, TP9.1 (1_1); also elsewhere on the board
UART4_TX: J1.1, J14.2, TP13.1 (1_1), TP19.1 (1_1), TP27.1 (1_1); also elsewhere on the board
UART5_RX: J10.2, TP30.1 (1_1); also elsewhere on the board
UART5_TX: J10.1, TP29.1 (1_1); also elsewhere on the board
UART7_RX: J9.4, TP26.1 (1_1); also elsewhere on the board
UART7_TX: J9.3, TP25.1 (1_1); also elsewhere on the board
VIDEO_CC: J13.4, TP35.1 (1_1); also elsewhere on the board
VIDEO_IN: J13.3, TP34.1 (1_1); also elsewhere on the board
VIDEO_OUT: J14.1, TP28.1 (1_1); also elsewhere on the board

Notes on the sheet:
ANALOG VTX
External LEDs
Buzzer
DJI Air Unit Connector
GPS
JST Connectors and TestPoints
ESC
Receiver
CAM

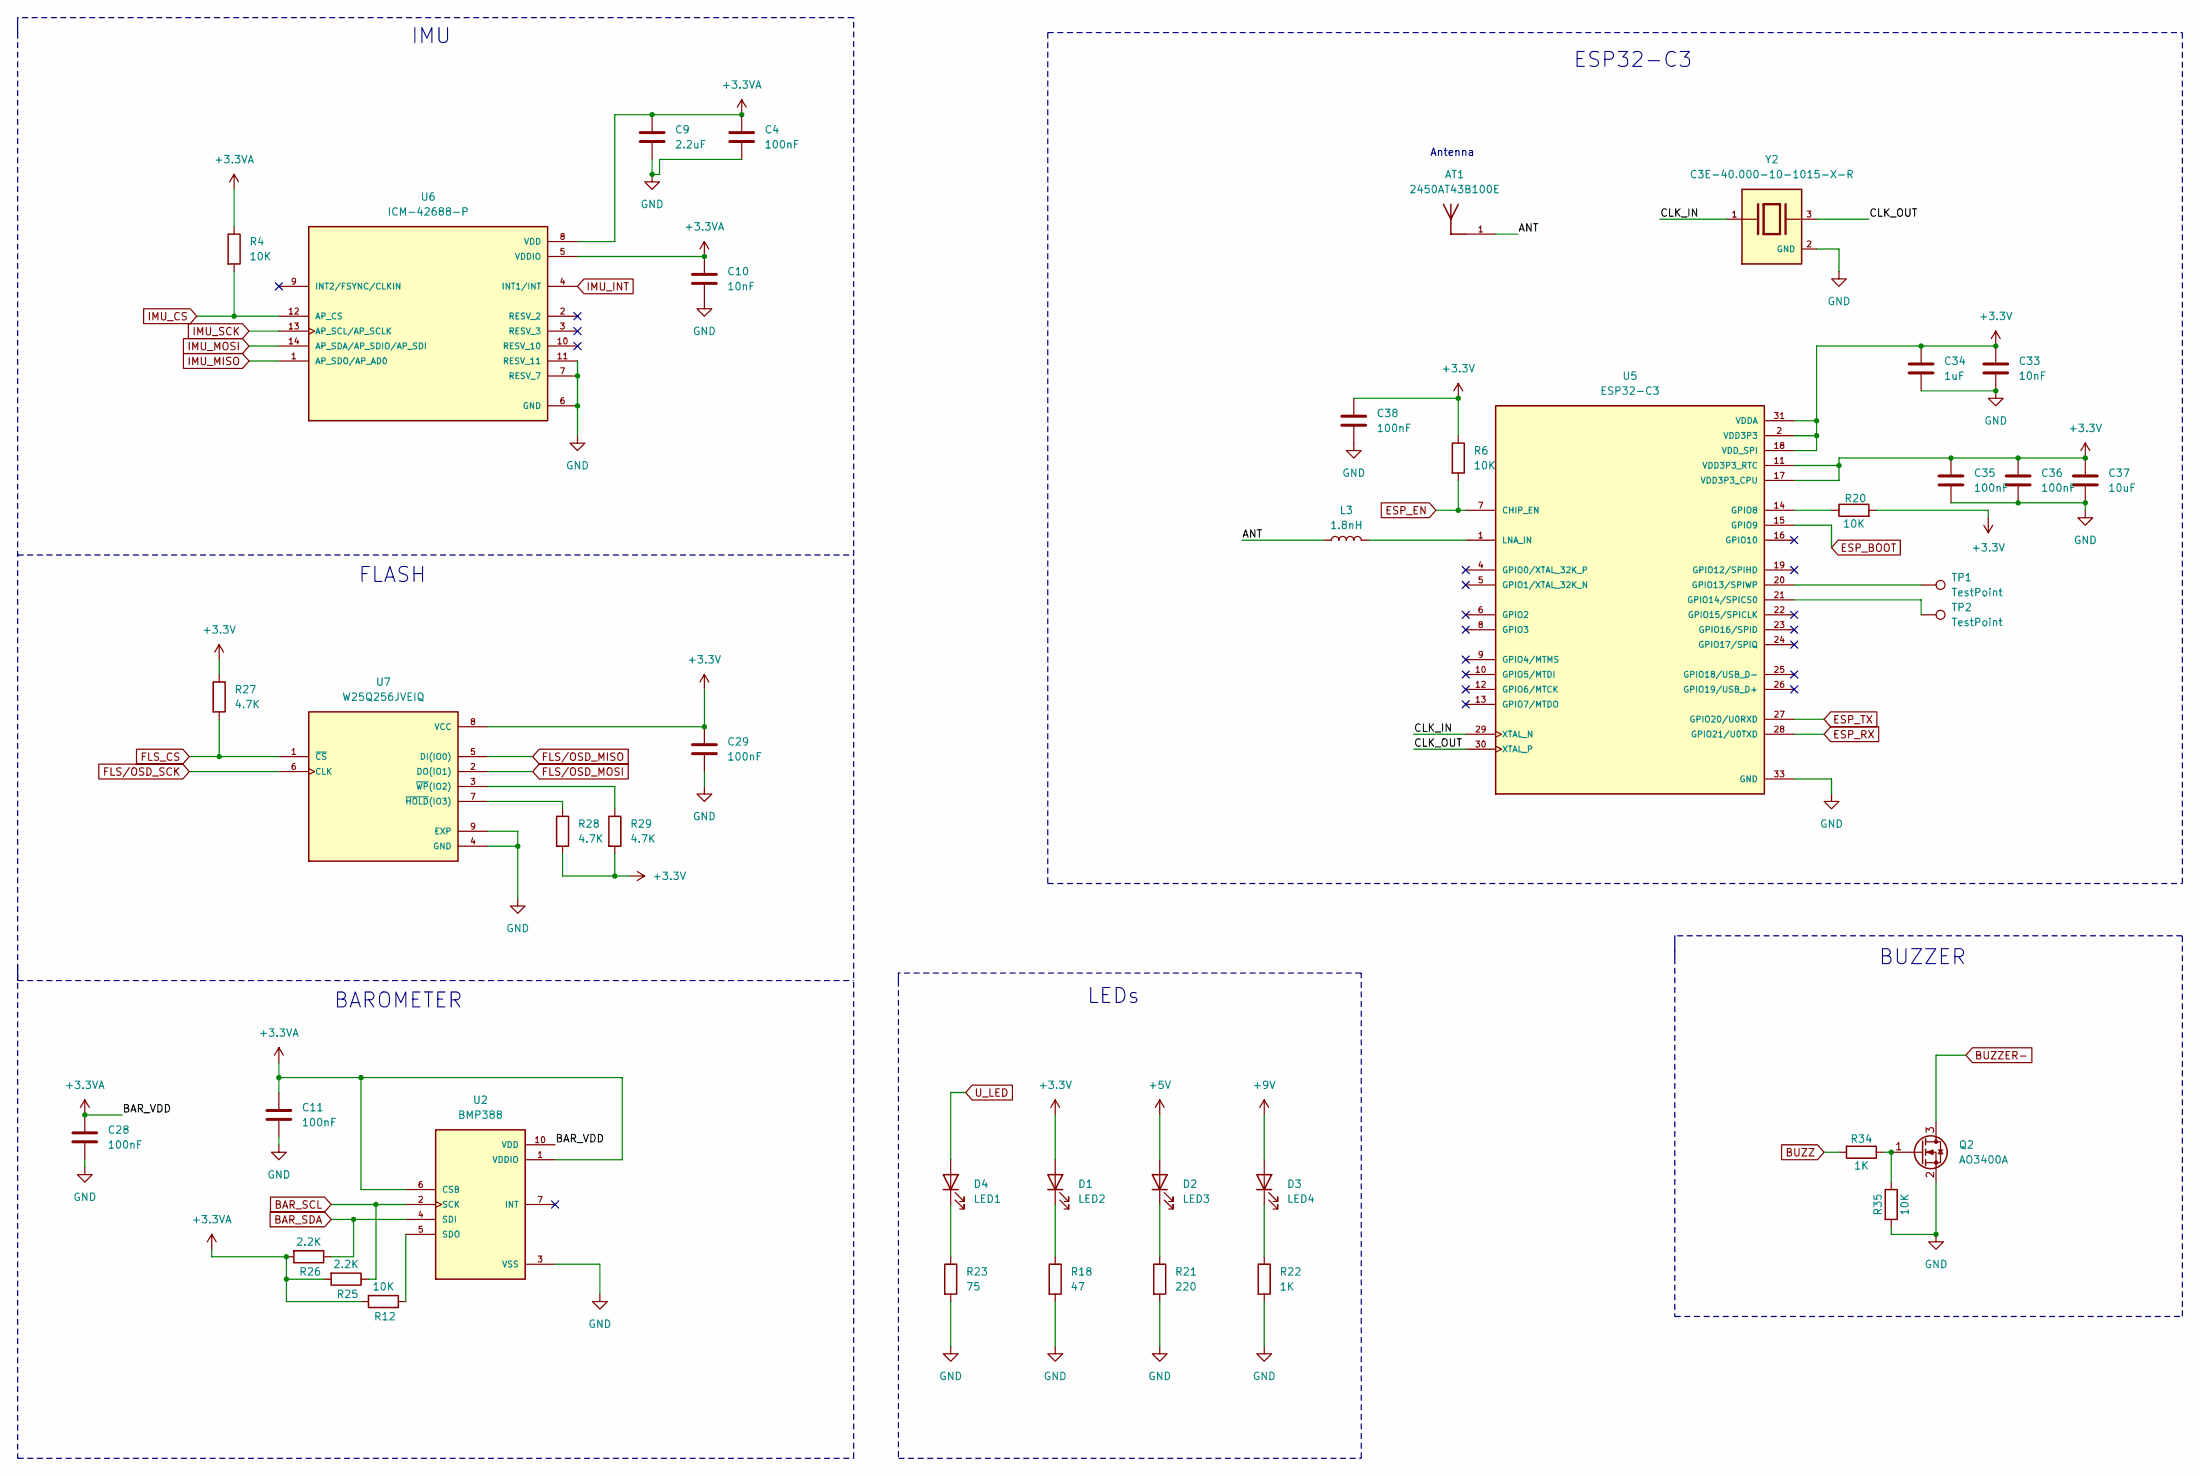
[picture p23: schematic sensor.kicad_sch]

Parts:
AT1: 2450AT43B100E; ANTENNA_2450AT43B100E; PARTREV N/A; LCSC C2917721
C4, C11, C28, C29, C35, C36, C38: 100nF; C_0402_1005Metric; MANUFACTURER PART NUMBER CL05A104KA5NNNC; LCSC C100072
C9: 2.2uF; C_0402_1005Metric; MANUFACTURER PART NUMBER CL05A225KP5NSNC; LCSC C107369
C10, C33: 10nF; C_0402_1005Metric; MANUFACTURER PART NUMBER CL05B103KB5NNNC; LCSC C15195
C34: 1uF; C_0402_1005Metric; MANUFACTURER PART NUMBER CL05A105KO5NNNC; LCSC C29266
C37: 10uF; C_0805_2012Metric; MANUFACTURER PART NUMBER CL21A106KBYQNNE; LCSC C2932476
D1: LED2; LED_0805_2012Metric; MANUFACTURER PART NUMBER KT-0805B; LCSC C2293
D2: LED3; LED_0805_2012Metric; MANUFACTURER PART NUMBER KT-0805Y; LCSC C2296
D3: LED4; LED_0805_2012Metric; MANUFACTURER PART NUMBER KT-0805G; LCSC C2297
D4: LED1; LED_0805_2012Metric; MANUFACTURER PART NUMBER KT-0805R; LCSC C2295
L3: 1.8nH; L_0402_1005Metric; MANUFACTURER PART NUMBER LQG15HS1N8S02D; LCSC C77107
Q2: AO3400A; SOT-23; MANUFACTURER PART NUMBER AO3400A; LCSC C20917
R4, R6, R12, R20, R35: 10K; R_0402_1005Metric; MANUFACTURER PART NUMBER RC0402JR-0710KL; LCSC C60489
R18: 47; R_0402_1005Metric; MANUFACTURER PART NUMBER RC0402FR-0747RL; LCSC C137973
R21: 220; R_0402_1005Metric; MANUFACTURER PART NUMBER RC0402FR-07220RL; LCSC C112291
R22, R34: 1K; R_0402_1005Metric; MANUFACTURER PART NUMBER RC0402FR-071KL; LCSC C106235
R23: 75; R_0402_1005Metric; MANUFACTURER PART NUMBER RC0402JR-0775RL; LCSC C137841
R25, R26: 2.2K; R_0402_1005Metric; MANUFACTURER PART NUMBER RC0402JR-072K2L; LCSC C163447
R27, R28, R29: 4.7K; R_0402_1005Metric; MANUFACTURER PART NUMBER RC0402FR-074K7L; LCSC C105871
TP1, TP2: TestPoint; TestPoint_Pad_D1.0mm
U2: BMP388; XDCR_BMP388; PARTREV 1.7; LCSC C779278
U5: ESP32-C3; QFN50P500X500X90-33N; PARTREV 2.0; LCSC C2838500
U6: ICM-42688-P; PQFN50P300X250X97-14N; PARTREV 1.2; LCSC C1850418, Mouser No: 410-ICM-42688-P
U7: W25Q256JVEIQ; IC_W25N04KVZEIR; PARTREV I; LCSC C97522
Y2: C3E-40.000-10-1015-X-R; XTAL_C3E-40.000-10-1015-X-R; PARTREV August 01, 2022; LCSC C5444549

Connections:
+3.3V: C29.1, C33.1, C34.1, C35.1, C36.1, C37.1, C38.1, D1.2 (A), R6.1, R20.2, R27.1, R28.2, R29.2, U5.2 (VDD3P3), U5.3 (VDD3P3), U5.11 (VDD3P3_RTC), U5.17 (VDD3P3_CPU), U5.18 (VDD_SPI), U5.31 (VDDA), U5.32 (VDDA), U7.8 (VCC); also elsewhere on the board
+3.3VA: C4.1, C9.1, C10.1, C11.1, C28.1, R4.1, R12.2, R25.2, R26.2, U2.1 (VDDIO), U2.6 (CSB), U2.10 (VDD), U6.5 (VDDIO), U6.8 (VDD); also elsewhere on the board
+5V: D2.2 (A); also elsewhere on the board
+9V: D3.2 (A); also elsewhere on the board
/Sensor Section/ANT: AT1.1, L3.1
/Sensor Section/CLK_IN: U5.29 (XTAL_N), Y2.1
/Sensor Section/CLK_OUT: U5.30 (XTAL_P), Y2.3
BAR_SCL: R25.1, U2.2 (SCK); also elsewhere on the board
BAR_SDA: R26.1, U2.4 (SDI); also elsewhere on the board
BUZZ: R34.2; also elsewhere on the board
BUZZER-: Q2.3 (D); also elsewhere on the board
ESP_BOOT: U5.15 (GPIO9); also elsewhere on the board
ESP_EN: R6.2, U5.7 (CHIP_EN); also elsewhere on the board
ESP_RX: U5.28 (GPIO21/U0TXD); also elsewhere on the board
ESP_TX: U5.27 (GPIO20/U0RXD); also elsewhere on the board
FLS_CS: R27.2, U7.1 (~CS); also elsewhere on the board
FLS/OSD_MISO: U7.5 (DI(IO0)); also elsewhere on the board
FLS/OSD_MOSI: U7.2 (DO(IO1)); also elsewhere on the board
FLS/OSD_SCK: U7.6 (CLK); also elsewhere on the board
GND: C4.2, C9.2, C10.2, C11.2, C28.2, C29.2, C33.2, C34.2, C35.2, C36.2, C37.2, C38.2, Q2.2 (S), R18.2, R21.2, R22.2, R23.2, R35.2, U2.3 (VSS), U2.8 (VSS), U2.9 (VSS), U5.33 (GND), U6.6 (GND), U6.7 (RESV_7), U6.11 (RESV_11), U7.4 (GND), U7.9 (EXP), Y2.2 (GND), Y2.4 (GND); also elsewhere on the board
IMU_CS: R4.2, U6.12 (AP_CS); also elsewhere on the board
IMU_INT: U6.4 (INT1/INT); also elsewhere on the board
IMU_MISO: U6.1 (AP_SDO/AP_AD0); also elsewhere on the board
IMU_MOSI: U6.14 (AP_SDA/AP_SDIO/AP_SDI); also elsewhere on the board
IMU_SCK: U6.13 (AP_SCL/AP_SCLK); also elsewhere on the board
unnamed: D1.1 (K), R18.1
unnamed: D2.1 (K), R21.1
unnamed: D3.1 (K), R22.1
unnamed: D4.1 (K), R23.1
unnamed: Q2.1 (G), R34.1, R35.1
unnamed: R12.1, U2.5 (SDO)
unnamed: R20.1, U5.14 (GPIO8)
unnamed: TP1.1 (1_1), U5.20 (GPIO13/SPIWP)
unnamed: TP2.1 (1_1), U5.21 (GPIO14/SPICS0)
unnamed: L3.2, U5.1 (LNA_IN)
unnamed: R28.1, U7.7 (~HOLD(IO3))
unnamed: R29.1, U7.3 (~WP(IO2))
U_LED: D4.2 (A); also elsewhere on the board

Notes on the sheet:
FLASH
BUZZER
BAROMETER
LEDs
IMU
ESP32-C3
Antenna

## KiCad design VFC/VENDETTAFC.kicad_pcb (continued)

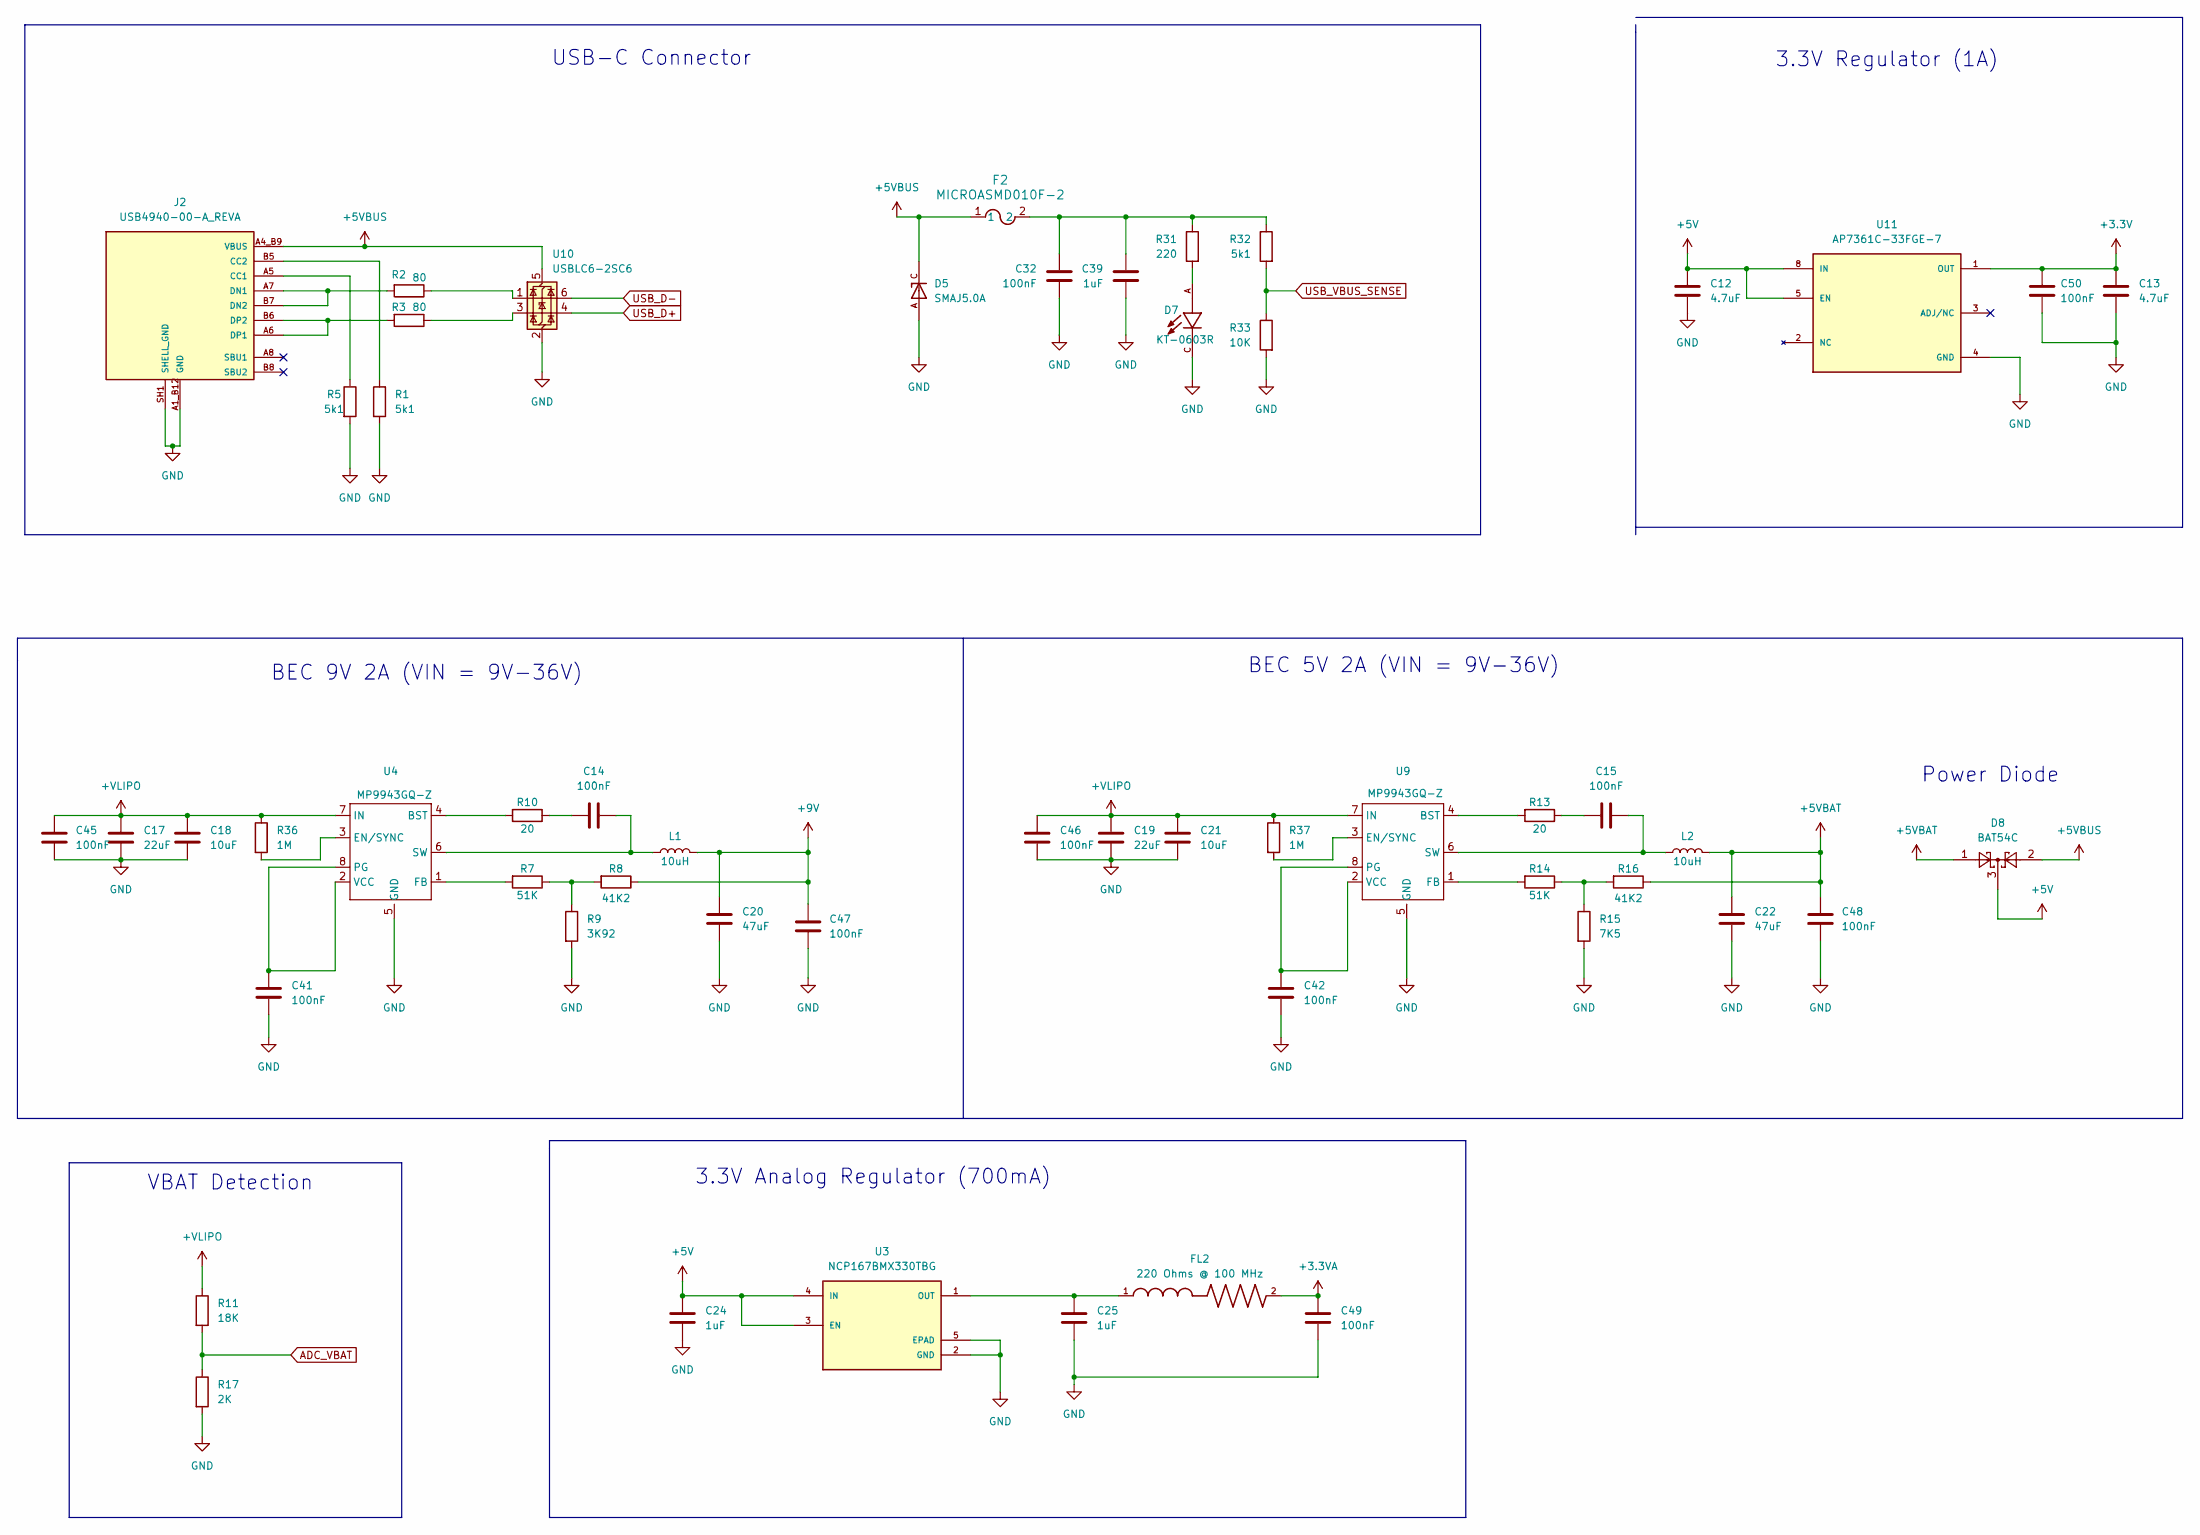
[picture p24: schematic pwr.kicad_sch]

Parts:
C12, C13: 4.7uF; C_0603_1608Metric; MANUFACTURER PART NUMBER CL10A475KO8NNNC; LCSC C19666
C14, C15, C32, C41, C42, C45, C46, C47, C48, C49, C50: 100nF; C_0402_1005Metric; MANUFACTURER PART NUMBER CL05A104KA5NNNC; LCSC C100072
C17, C19: 22uF; C_0805_2012Metric; MANUFACTURER PART NUMBER HGC0805R5226M350NSLJ; LCSC C22367832
C18, C21: 10uF; C_0805_2012Metric; MANUFACTURER PART NUMBER CL21A106KBYQNNE; LCSC C2932476
C20, C22: 47uF; C_0805_2012Metric; MANUFACTURER PART NUMBER CL21A476MPYNNWE; LCSC C5596752
C24, C25, C39: 1uF; C_0402_1005Metric; MANUFACTURER PART NUMBER CL05A105KO5NNNC; LCSC C29266
D5: SMAJ5.0A; DIOM4325X250N; PARTREV S2102; LCSC C83329
D7: KT-0603R; LED_KT-0603R; PARTREV 2013/01/24; LCSC C2286
D8: BAT54C; SOT-23; MANUFACTURER PART NUMBER BAT54CLT1G; LCSC C14308
F2: MICROASMD010F-2; FUSE_MICROASMD010F_LTF; MANUFACTURER PART NUMBER MICROSMD010F-2; LCSC C2649903
FL2: 220 Ohms @ 100 MHz; L_0402_1005Metric; MANUFACTURER PART NUMBER BLM15BB221SN1D; LCSC C85818
J2: USB4940-00-A_REVA; GCT_USB4940-00-A_REVA; PARTREV A; LCSC C54829818
L1, L2: 10uH; L_Changjiang_FTC404020S; MANUFACTURER PART NUMBER GXTC0420-100-MT; LCSC C53198553
R1, R5, R32: 5k1; R_0402_1005Metric; MANUFACTURER PART NUMBER RC0402FR-075K1L; LCSC C105872
R2, R3: 80; R_0402_1005Metric; MANUFACTURER PART NUMBER RC0402FR-0780R6L; LCSC C185392
R7, R14: 51K; R_0402_1005Metric; MANUFACTURER PART NUMBER RC0402FR-0751KL; LCSC C107229
R8, R16: 41K2; R_0402_1005Metric; MANUFACTURER PART NUMBER CRCW040241K2FKED; LCSC C844310
R9: 3K92; R_0402_1005Metric; MANUFACTURER PART NUMBER RC0402FR-073K9L; LCSC C131467
R10, R13: 20; R_0402_1005Metric; MANUFACTURER PART NUMBER RC0402FR-0720RL; LCSC C138031
R11: 18K; R_0402_1005Metric; MANUFACTURER PART NUMBER 0402WGF1802TCE; LCSC C25762
R15: 7K5; R_0402_1005Metric; MANUFACTURER PART NUMBER 0402WGF7501TCE; LCSC C25918
R17: 2K; R_0402_1005Metric; MANUFACTURER PART NUMBER RC0402FR-072KL; LCSC C60488
R31: 220; R_0402_1005Metric; MANUFACTURER PART NUMBER RC0402FR-07220RL; LCSC C112291
R33: 10K; R_0402_1005Metric; MANUFACTURER PART NUMBER RC0402JR-0710KL; LCSC C60489
R36, R37: 1M; R_0402_1005Metric; MANUFACTURER PART NUMBER RC0402JR-071ML; LCSC C93949
U3: NCP167BMX330TBG; VREG_NCP167BMX330TBG; PARTREV 5; LCSC C892227
U4, U9: MP9943GQ-Z; QFN-8_MP9943_MNP; MANUFACTURER PART NUMBER MP9943GQ-Z; LCSC Mouser No: 946-MP9943GQ-Z
U10: USBLC6-2SC6; SOT-23-6; MANUFACTURER PART NUMBER USBLC6-2SC6; LCSC C7519
U11: AP7361C-33FGE-7; SON65P300X300X63-9N; PARTREV 5 - 2; LCSC C151007

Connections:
+3.3V: C13.1, C50.1, U11.1 (OUT); also elsewhere on the board
+3.3VA: C49.1, FL2.2; also elsewhere on the board
+5V: C12.1, C24.1, D8.3, U3.3 (EN), U3.4 (IN), U11.5 (EN), U11.8 (IN); also elsewhere on the board
+5VBAT: C22.1, C48.1, D8.1, L2.2, R16.1
+5VBUS: D5.C, D8.2, F2.1, J2.A4_B9 (VBUS), J2.B4_A9 (VBUS), U10.5 (VBUS)
+9V: C20.1, C47.1, L1.2, R8.1; also elsewhere on the board
+VLIPO: C17.1, C18.1, C19.1, C21.1, C45.1, C46.1, R11.1, R36.1, R37.1, U4.7 (IN), U9.7 (IN); also elsewhere on the board
ADC_VBAT: R11.2, R17.1; also elsewhere on the board
GND: C12.2, C13.2, C17.2, C18.2, C19.2, C20.2, C21.2, C22.2, C24.2, C25.2, C32.2, C39.2, C41.2, C42.2, C45.2, C46.2, C47.2, C48.2, C49.2, C50.2, D5.A, D7.C, J2.A1_B12 (GND), J2.B1_A12 (GND), J2.SH1 (SHELL_GND), J2.SH2 (SHELL_GND), J2.SH3 (SHELL_GND), J2.SH4 (SHELL_GND), R1.2, R5.2, R9.2, R15.2, R17.2, R33.2, U3.2 (GND), U3.5 (EPAD), U4.5 (GND), U9.5 (GND), U10.2 (GND), U11.4 (GND), U11.9 (GND); also elsewhere on the board
unnamed: C14.2, R10.1
unnamed: C15.2, R13.1
unnamed: C32.1, C39.1, F2.2, R31.1, R32.1
unnamed: D7.A, R31.2
unnamed: J2.A5 (CC1), R5.1
unnamed: J2.B5 (CC2), R1.1
unnamed: J2.A7 (DN1), J2.B7 (DN2), R2.2
unnamed: J2.A6 (DP1), J2.B6 (DP2), R3.2
unnamed: R2.1, U10.1 (I/O1)
unnamed: R3.1, U10.3 (I/O2)
unnamed: R7.1, R8.2, R9.1
unnamed: R14.1, R15.1, R16.2
unnamed: C25.1, FL2.1, U3.1 (OUT)
unnamed: R10.2, U4.4 (BST)
unnamed: R36.2, U4.3 (EN/SYNC)
unnamed: R7.2, U4.1 (FB)
unnamed: C41.1, U4.2 (VCC), U4.8 (PG)
unnamed: C14.1, L1.1, U4.6 (SW)
unnamed: R13.2, U9.4 (BST)
unnamed: R37.2, U9.3 (EN/SYNC)
unnamed: R14.2, U9.1 (FB)
unnamed: C42.1, U9.2 (VCC), U9.8 (PG)
unnamed: C15.1, L2.1, U9.6 (SW)
USB_D+: U10.4 (I/O2); also elsewhere on the board
USB_D-: U10.6 (I/O1); also elsewhere on the board
USB_VBUS_SENSE: R32.2, R33.1; also elsewhere on the board

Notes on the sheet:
USB-C Connector
3.3V Analog Regulator (700mA)
VBAT Detection
BEC 5V 2A (VIN = 9V-36V)
BEC 9V 2A (VIN = 9V-36V)
Power Diode
3.3V Regulator (1A)

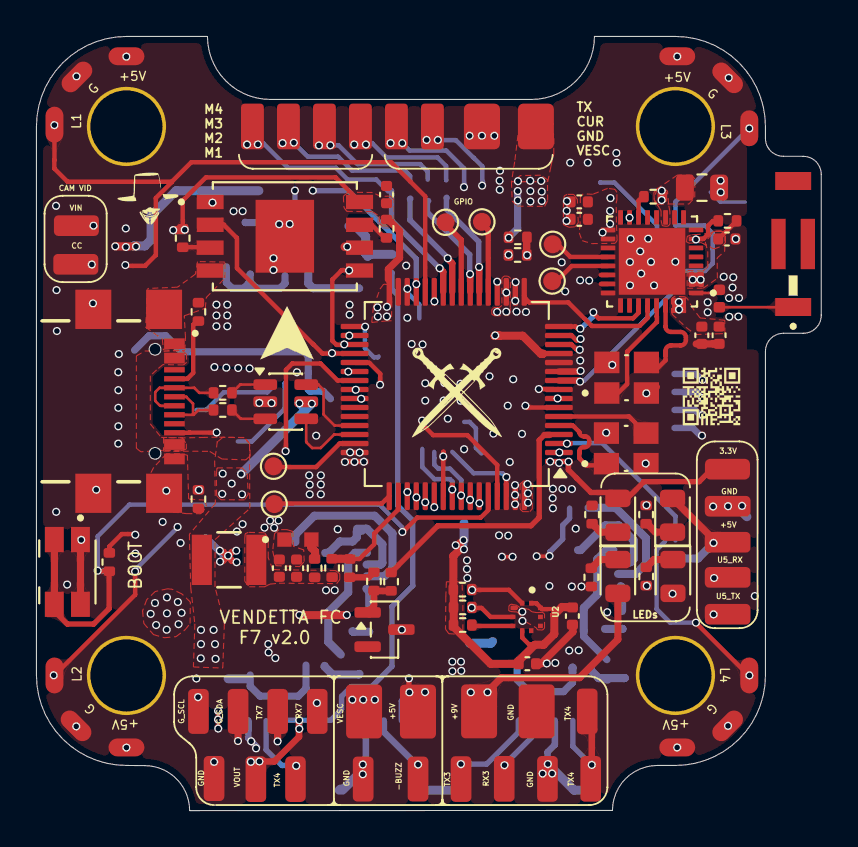
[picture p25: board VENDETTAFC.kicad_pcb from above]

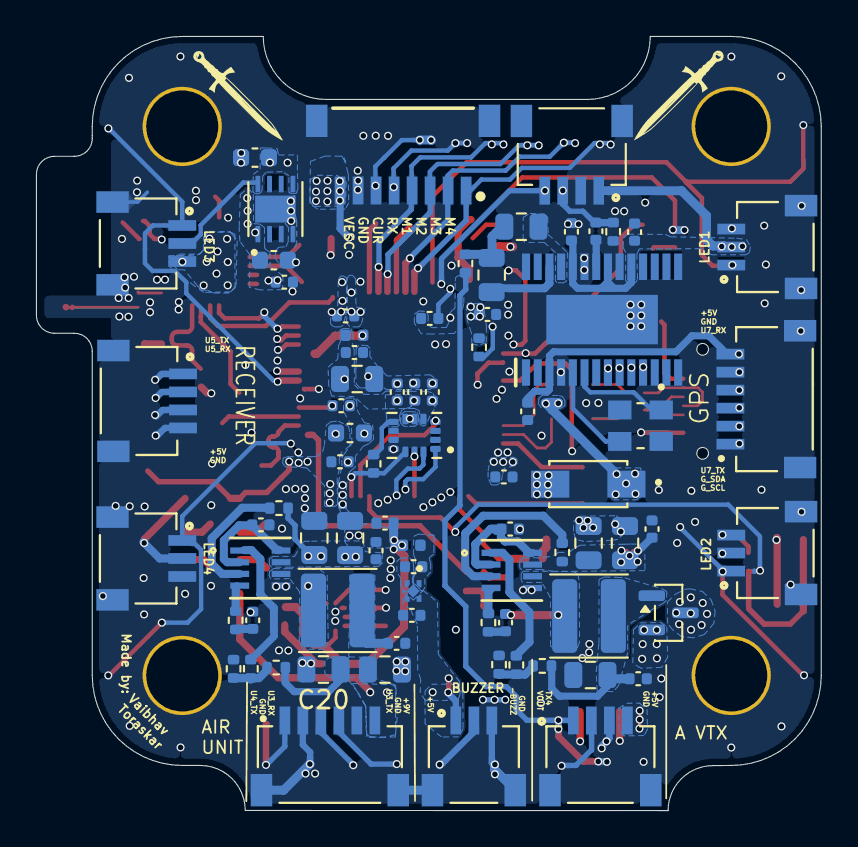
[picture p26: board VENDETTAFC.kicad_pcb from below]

Board: 6 copper layers, 43.6 x 43.0 mm, 180 parts (77 on the bottom side), 107 nets.

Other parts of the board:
TP36#2: TestPoint; TestPoint_Pad_1.0x1.0mm

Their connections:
GND: TP36#2.1 (1_1); also elsewhere on the board

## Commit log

2026-04-30 added VESC (revision_1)
    [ESC1.kicad_sch, VENDETTAESC.kicad_pcb, VENDETTAESC.kicad_sch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]
2026-04-30 Update README.md for VESC
2026-05-02 Revision_2 of VESC
    [VENDETTAESC.kicad_pcb, VENDETTAESC.kicad_sch]
2026-05-02 Added BOM, gerbers
    [ESC1.kicad_sch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]
2026-05-06 Updated VFC schematic
    [VENDETTAFC.kicad_pcb, VENDETTAFC.kicad_sch, interface.kicad_sch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]
2026-05-08 VFC PCB components placements complete
    [VENDETTAFC.kicad_pcb, VENDETTAFC.kicad_sch, interface.kicad_sch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]
2026-05-09 VFC PCB traces update
    [VENDETTAFC.kicad_pcb, VENDETTAFC.kicad_sch, pwr.kicad_sch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]
2026-05-10 Revision_1 of VFC complete
    [ESC1.kicad_sch, VENDETTAESC.kicad_sch, VENDETTAFC.kicad_pcb]
2026-05-10 Added LICENSE
    [ESC1.kicad_sch, VENDETTAESC.kicad_pcb, VENDETTAESC.kicad_sch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]
2026-05-22 Added fabrication files
    [ESC1.kicad_sch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]
2026-05-23 Routing improvements
    [VENDETTAFC-B_Cu.gbr, VENDETTAFC-B_Mask.gbr, VENDETTAFC-B_Paste.gbr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]
2026-05-28 Added telemetery feature for ESC
    [ESC1.kicad_sch, VENDETTAESC.kicad_pcb, VENDETTAESC.kicad_sch]
2026-05-29 VESC Revision 2.0
    [ESC1.kicad_sch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]
2026-05-30 VFC Revision 2.0
    [VENDETTAFC.kicad_pcb, interface.kicad_sch, pwr.kicad_sch]
2026-06-01 Rev 2.0 fabrication documentation
    [ESC1.kicad_sch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]

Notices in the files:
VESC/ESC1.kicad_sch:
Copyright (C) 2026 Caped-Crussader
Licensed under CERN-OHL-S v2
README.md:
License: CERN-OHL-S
